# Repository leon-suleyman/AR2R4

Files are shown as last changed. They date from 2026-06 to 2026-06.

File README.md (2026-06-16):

# AR2R4

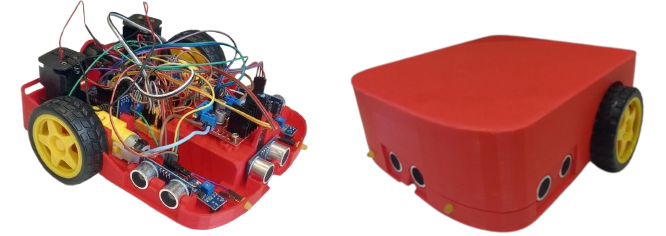
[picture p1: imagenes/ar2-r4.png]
Foto del robot AR2R4 con y sin la tapa puesta


El AR2R4 es un robot educativo de diseño abierto basado en
la placa Arduino UNO R4, orientado específicamente a la
enseñanza progresiva de programación y robótica móvil.
El robot fue concebido con el objetivo de ofrecer una
plataforma de muy bajo costo (se estima que el costo total es
USD 120, a precios de mayo de 2026), fácilmente reproducible
mediante impresión 3D y componentes comerciales accesibles,
pero al mismo tiempo suficientemente flexible como para cu-
brir distintos niveles de complejidad educativa y tecnológica.

## Componentes

Esta tabla contiene todos los componentes necesarios, el modelo utilizado y la cantidad necesaria para armar el AR2R4 cuyo modelo 3D está compartido en este repositorio.

| Componente | Modelo | Cantidad |
| --- | --- | --- |
| Arduino | UNO R4 | 1 |
| Puente H | L298N | 1 |
| Sensor óptico | LM393 | 2 |
| Sonar | HC-SR04 | 3 |
| Módulo IR | TCRT5000 | 2 |
| Resistencia | 10 $\Omega$, 1/4 W | 3 |
| Capacitor | 470 $\mu F$, 16 V | 1 |
| LED | 5mm | 3 |
| Motor DC | 3--6 V, doble eje | 2 |
| Rueda motriz | 68x26mm | 2 |
| Disco encoder | 25.5mm, 20 ranuras | 2 |
| Rueda castor | 25 mm | 1 |
| Breadboard | 170 puntos | 1 |
| Cable Dupont | 10cm macho-hembra | 34 |
| Cable Dupont | 10cm macho-macho | 13 |
| Cable | 1.5x100mm | 6 |
| Interruptor | 20mm | 1 |
| Tornillo | 3x12mm auto-perf. | 12 |
| Tornillo | 3x12mm cabeza plana | 2 |
| Tornillo | 3x30mm cabeza plana | 4 |
| Tuerca | 3mm | 6 |
| Porta pilas | 4xAA | 2 |
| Pila recargable | AA, 2700mAh | 8 |
| Chasis | PLA, 250g | 1 |

Al ser imprimible, el chasis puede ser modificado desde su modelo 3D y queda abierto a que modifiquen el AR2R4 de la manera que más les interese.

## Circuito

También les dejamos una imagen mostrando todas las conexiones eléctricas de este modelo del AR2R4, para que puedan recrearlo. Tengan en cuenta que los cables más gruesos son para conectar los motores al driver y el driver a las baterías.

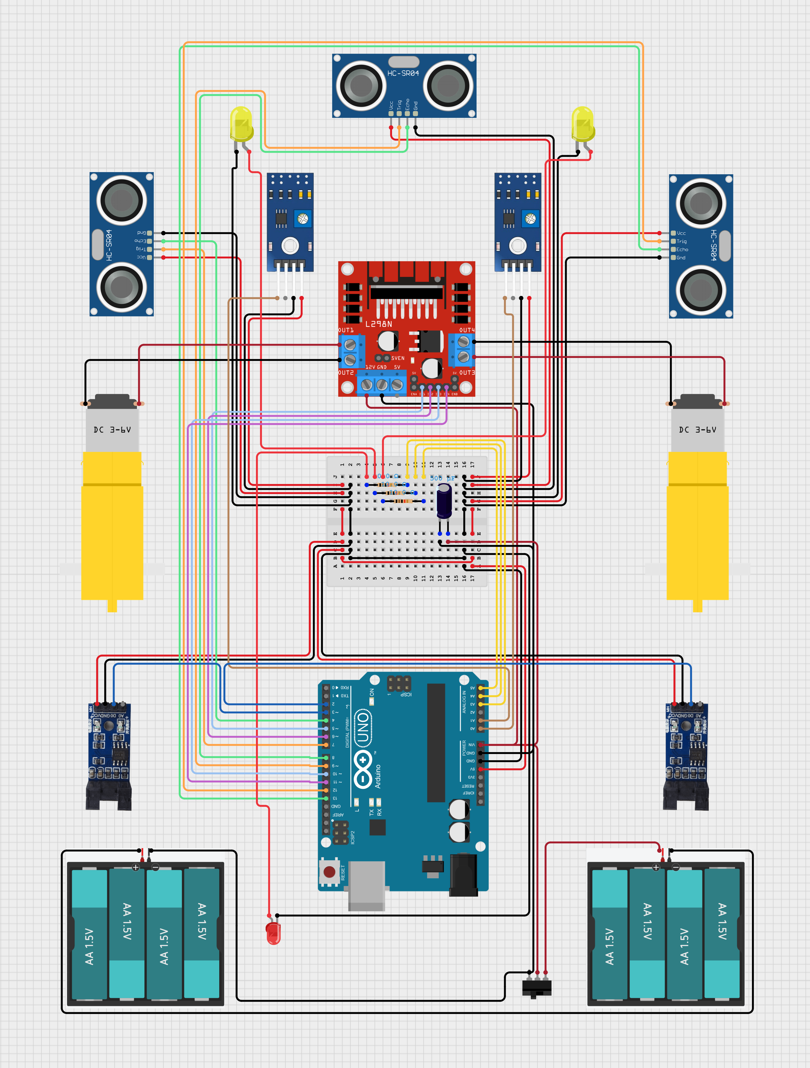
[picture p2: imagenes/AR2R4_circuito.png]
Diagrama de las conexiones de los componentes electrónicos del robot AR2R4


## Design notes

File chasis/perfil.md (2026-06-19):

# Perfil de impresión recomendado
* **IMPORTANTE**: En Orca y en BambuLab activar *Detect Thin Wall* (de otra forma, algunas secciones no se van a imprimir correctamente).
* Imprimir sin soportes (los modelos ya incluyen soportes).
* Imprimir sin infill (algunas secciones de los modelo son más delgadas intencionalmente, porque es donde se colocan los tornillos autoperforantes).
* Altura de capa: 0.2 mm.
* Altura de capa inicial: 0.4 mm.
* Capas de techo: 5.
* Capas de piso: 5.

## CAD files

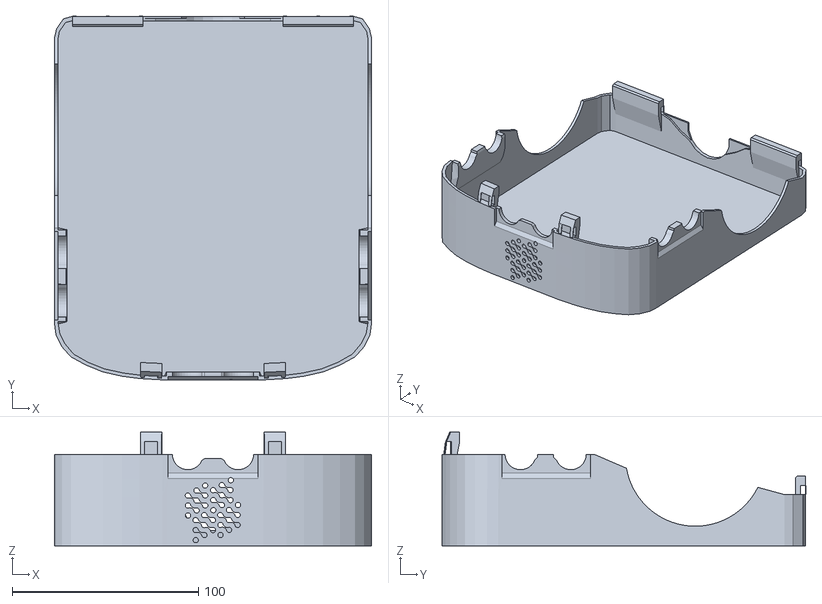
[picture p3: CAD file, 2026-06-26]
chasis/Tapa1.8.stl
170.0 x 195.1 x 60.9

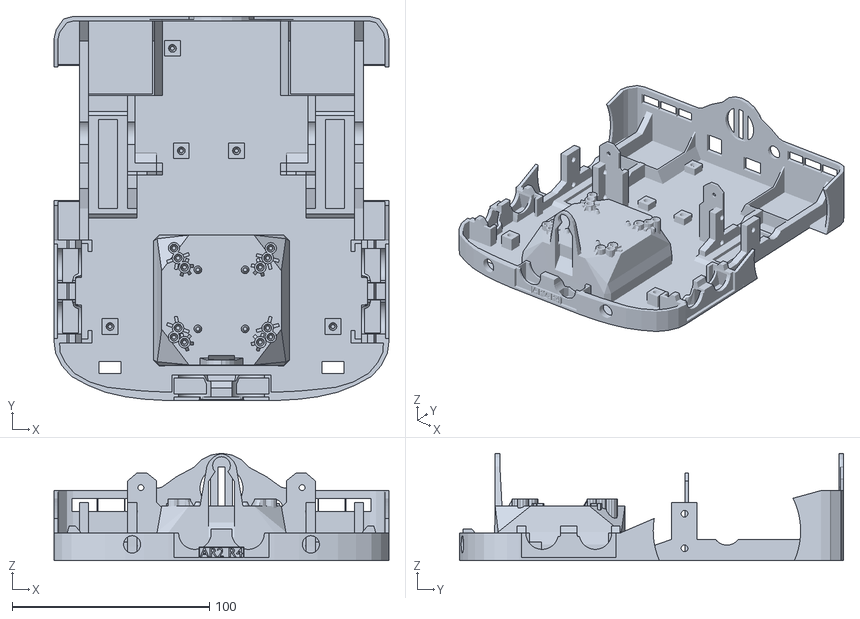
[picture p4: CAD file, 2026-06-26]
chasis/Base1.8.stl
170.0 x 195.0 x 54.5

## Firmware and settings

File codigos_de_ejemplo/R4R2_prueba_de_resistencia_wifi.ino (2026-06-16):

#include <Arduino.h>
#include <micro_ros_arduino.h>

#include <stdio.h>
#include <rcl/rcl.h>
#include <rcl/error_handling.h>
#include <rclc/rclc.h>
#include <rclc/executor.h>

#include <std_msgs/msg/float32.h>
#include <std_msgs/msg/int32.h>
#include <geometry_msgs/msg/twist.h>


/* ---- Pines motores (PWM) ---- */
#define PIN_MOTOR_IZQ_A 5
#define PIN_MOTOR_IZQ_B 6
#define PIN_MOTOR_DER_A 10
#define PIN_MOTOR_DER_B 11

/* ---- Pines encoders (interrupciones UNO) ---- */
#define PIN_ENCODER_DER 2  // INT0
#define PIN_ENCODER_IZQ 3   // INT1

/* ---- Pines sonares ---- */
#define T_SONAR_F 9
#define E_SONAR_F 8
#define T_SONAR_I 7
#define E_SONAR_I 4
#define T_SONAR_D 12
#define E_SONAR_D 13

/* ---- LEDs delanteros ---- */
#define LED_T A3
#define LED_IZQ A4
#define LED_DER A5

/* ---- Constantes sonar / comportamiento ---- */
const float DISTANCIA_SIN_ECO = 10000.0;
const float DIST_LLEGO_CM     = 5.0;    // <= 5 cm: llegó
const float DIST_MAX_DET_CM   = 50.0;   // si está más lejos: “no detecta”
const unsigned long BLINK_MS  = 200;    // parpadeo LEDs mientras se acerca

/* ---- PID / control ---- */
#define PWM_MAX 255
#define PWM_MIN_DER 30
#define PWM_MIN_IZQ 30
#define P 40.0
#define I 20.0
#define D 4.0
#define TIEMPO_CONTROL 50UL  // ms
#define VEL_BAJA 0.5
#define VEL_MEDIA 0.7
#define VEL_ALTA 0.9

static const int RANURAS_POR_VUELTA = 20; // 20 ticks = 1 vuelta

/*Medidas del coche (en metros)*/
#define DISTANCIA_ENTRE_RUEDAS 0.204
#define RADIO_DE_LAS_RUEDAS 0.0325

#if !defined(ESP32) && !defined(TARGET_PORTENTA_H7_M7) && !defined(ARDUINO_GIGA) && !defined(ARDUINO_NANO_RP2040_CONNECT) && !defined(ARDUINO_WIO_TERMINAL) && !defined(ARDUINO_UNOR4_WIFI) && !defined(ARDUINO_OPTA)
#error This example is only available for Arduino Portenta, Arduino Giga R1, Arduino Nano RP2040 Connect, ESP32 Dev module, Wio Terminal, Arduino Uno R4 WiFi and Arduino OPTA WiFi 
#endif

#if defined(LED_BUILTIN)
  #define LED_PIN LED_BUILTIN
#else
  #define LED_PIN 13
#endif

#define RCCHECK(fn) { rcl_ret_t temp_rc = fn; if((temp_rc != RCL_RET_OK)){error_loop();}}
#define RCSOFTCHECK(fn) { rcl_ret_t temp_rc = fn; if((temp_rc != RCL_RET_OK)){digitalWrite(LED_T, HIGH); delay(500); digitalWrite(LED_T, LOW);}}

/* Constantes de configuración */
float acumuladas_frontales[3] = {0,0,0};
int indice_frontales = 0;
float acumuladas_izquierdas[3] = {0,0,0};
int indice_izquierdas = 0;
float acumuladas_derechas[3] = {0,0,0};
int indice_derechas = 0;

/* ---- Estados y sonares ---- */
enum SONARES { SONAR_FRONTAL, SONAR_IZQ, SONAR_DER };
enum ESTADOS {AVANZAR, GIRAR_DER, GIRAR_IZQ, RETROCEDER};

ESTADOS estado = AVANZAR;

/* ---- Encoder ticks (ISR) ---- */
volatile long ticks_derecha = 0;
volatile long ticks_izquierda = 0;

/* Dirección recordada para dar signo a ticks
   Convención del robot (como tu actividad 5):
   - PWM NEGATIVO = ADELANTE
   - PWM POSITIVO = ATRÁS
   Para que la velocidad real sea POSITIVA cuando avanza,
   guardamos dir = +1 cuando PWM es negativo (adelante). */
volatile int8_t dir_der = +1; // +1 = adelante, -1 = atrás
volatile int8_t dir_izq = +1;

/* PID por rueda */
double integral_I_der = 0.0;
double integral_I_izq = 0.0;
double error_anterior_der = 0.0;
double error_anterior_izq = 0.0;

unsigned long tiempo_desde_control = 0;

/*variables de odometria*/
double posicion_x = 0.0;
double posicion_y = 0.0;
double posicion_theta = 0.0;

double velocidad_actual_lineal = 0.0;
double velocidad_actual_angular = 0.0;

/* Parpadeo LEDs */
unsigned long lastBlink = 0;
bool blinkOn = false;

/* Setpoints (velocidad deseada en grados/ms, SIEMPRE >= 0 para avanzar) */
double vel_deseada_der = 0.0;
double vel_deseada_izq = 0.0;

/* variables de micro-ros, publicadores y subscriptores */
String ros_namespace = "AR2R4";

rclc_support_t support;
rcl_allocator_t allocator;
rcl_node_t node;

rcl_publisher_t publisher_sonar_frontal;
std_msgs__msg__Float32 msg_sonar_frontal;
rcl_publisher_t publisher_sonar_derecho;
std_msgs__msg__Float32 msg_sonar_derecho;
rcl_publisher_t publisher_sonar_izquierdo;
std_msgs__msg__Float32 msg_sonar_izquierdo;

rcl_publisher_t publisher_velocidad_derecha;
std_msgs__msg__Float32 msg_velocidad_derecha;
rcl_publisher_t publisher_velocidad_izquierda;
std_msgs__msg__Float32 msg_velocidad_izquierda;

/*
rcl_publisher_t publisher_IR_derecho;
std_msgs__msg__Float32 msg_IR_derecho;
rcl_publisher_t publisher_IR_izquierdo;
std_msgs__msg__Float32 msg_IR_izquierdo;
*/

rcl_publisher_t publisher_odometria;
geometry_msgs__msg__Twist msg_odometria;

/* Prototipos */
void tick_encoder_derecha();
void tick_encoder_izquierda();

float sonar(int trigger, int echo);
float medir_sonar(int trigger, int echo, float acumuladas[], int &indice_acumuladas, rcl_publisher_t &publisher, std_msgs__msg__Float32 &msg);
float revisarSonares(int id_sonar);
bool detectaObjetivo(float d_cm);

void setup_micro_ros();

double calcular_velocidad(long ticks, unsigned long tiempo_ms);
void control_PID(const unsigned long dt_ms);
int ciclo_control_PID_mag(double vel_deseada, double vel_real,
                          double& integral_I, double& error_previo);

void aplicar_PWM(int pwm_izq, int pwm_der);
void aplicar_PWM_a_motor(int pwm, uint8_t pin_A, uint8_t pin_B);

void cambiar_estado(int sonarActivo, float distActiva);

void calcular_posicion_actual(const unsigned long dt_ms);

void error_loop(){
  while(1){
    digitalWrite(LED_T, !digitalRead(LED_T));
    digitalWrite(LED_DER, !digitalRead(LED_DER));
    digitalWrite(LED_IZQ, !digitalRead(LED_IZQ));
    delay(100);
  }
}

/*
void timer_callback(rcl_timer_t * timer, int64_t last_call_time)
{
  RCLC_UNUSED(last_call_time);
  if (timer != NULL) {
    RCSOFTCHECK(rcl_publish(&publisher, &msg, NULL));
  }
}
*/

int tiempo_giro = 0;

/* =========================
   SETUP
   ========================= */
void setup() {
  pinMode(PIN_MOTOR_IZQ_A, OUTPUT);
  pinMode(PIN_MOTOR_IZQ_B, OUTPUT);
  pinMode(PIN_MOTOR_DER_A, OUTPUT);
  pinMode(PIN_MOTOR_DER_B, OUTPUT);

  pinMode(T_SONAR_I, OUTPUT); pinMode(E_SONAR_I, INPUT);
  pinMode(T_SONAR_F, OUTPUT); pinMode(E_SONAR_F, INPUT);
  pinMode(T_SONAR_D, OUTPUT); pinMode(E_SONAR_D, INPUT);

  pinMode(LED_T, OUTPUT);
  pinMode(LED_IZQ, OUTPUT);
  pinMode(LED_DER, OUTPUT);

  pinMode(PIN_ENCODER_DER, INPUT);
  pinMode(PIN_ENCODER_IZQ, INPUT);

  attachInterrupt(digitalPinToInterrupt(PIN_ENCODER_DER), tick_encoder_derecha, RISING);
  attachInterrupt(digitalPinToInterrupt(PIN_ENCODER_IZQ), tick_encoder_izquierda, RISING);

  //Serial.begin(9600);
  digitalWrite(LED_T, HIGH);
  delay(500);
  digitalWrite(LED_T, LOW);
  setup_micro_ros();
  
  aplicar_PWM(0, 0);
  tiempo_desde_control = millis();
  vel_deseada_der = -VEL_MEDIA;
  vel_deseada_izq = VEL_MEDIA;
  estado = GIRAR_IZQ;
  //aplicar_PWM(0,53);
}

/* =========================
   LOOP
   ========================= */
void loop() {

  //revisamos nuestros sonares y vemos si tenemos objetos cercanos 
  float sonar_frontal = revisarSonares(SONAR_FRONTAL);
  float sonar_izquierdo = revisarSonares(SONAR_IZQ);
  float sonar_derecho = revisarSonares(SONAR_DER);
  //Serial.print("frontal: "); Serial.print(sonar_frontal);Serial.print("izquierdo: "); Serial.print(sonar_izquierdo);Serial.print("derecho: "); Serial.println(sonar_derecho);

  bool obj_frente = hay_algo_cerca(sonar_frontal);
  bool obj_izquierda = hay_algo_cerca(sonar_izquierdo);
  bool obj_derecha = hay_algo_cerca(sonar_derecho);

  
  //en base a que objetos tenemos cercanos, cambiamos nuestro estado
  cambiar_estado(obj_frente, obj_izquierda, obj_derecha);
  long tiempo = millis();
  if (tiempo - tiempo_desde_control >= TIEMPO_CONTROL) {
    long dt_ms = tiempo - tiempo_desde_control;
    tiempo_desde_control = tiempo;
    calcular_posicion_actual(dt_ms);
    control_PID(dt_ms);
  }
}

void setup_micro_ros(){
  //parametros de set_microros_wifi_transorts: ("Nombre de red WIFI a conectar", "Contraseña de red WIFI", "IP de la computadora donde corre el agente de micro-ros donde comunicar", "puerto por el que el agente de micro-ros está conectado")
  set_microros_wifi_transports("EVENTO", "UBA-2022", "10.142.7.135", 8888);

  //Señal de que se conectó bien a la red WiFi
  digitalWrite(LED_T, HIGH);
  delay(500);
  digitalWrite(LED_T, LOW);
  //delay para estabilizar conexión con el agente de micro-ros
  delay(1500);

  allocator = rcl_get_default_allocator();

  //create init_options
  RCCHECK(rclc_support_init(&support, 0, NULL, &allocator));

  // create node
  RCCHECK(rclc_node_init_default(&node, "AR2R4", "", &support));
  String topic_name = "";

  // create publisher
  topic_name = ros_namespace + "/sonar_frontal";
  RCCHECK(rclc_publisher_init_best_effort(
    &publisher_sonar_frontal,
    &node,
    ROSIDL_GET_MSG_TYPE_SUPPORT(std_msgs, msg, Float32), 
    topic_name.c_str()));

  msg_sonar_frontal.data = 0.0;

  topic_name = ros_namespace + "/sonar_derecho";
  RCCHECK(rclc_publisher_init_best_effort(
    &publisher_sonar_derecho,
    &node,
    ROSIDL_GET_MSG_TYPE_SUPPORT(std_msgs, msg, Float32),
    topic_name.c_str()));

  msg_sonar_derecho.data = 0.0;
  
  topic_name = ros_namespace + "/sonar_izquierdo";
  RCCHECK(rclc_publisher_init_best_effort(
    &publisher_sonar_izquierdo,
    &node,
    ROSIDL_GET_MSG_TYPE_SUPPORT(std_msgs, msg, Float32),
    topic_name.c_str()));

  msg_sonar_izquierdo.data = 0.0;

  topic_name = ros_namespace + "/velocidad_derecha";
  RCCHECK(rclc_publisher_init_best_effort(
    &publisher_velocidad_derecha,
    &node,
    ROSIDL_GET_MSG_TYPE_SUPPORT(std_msgs, msg, Float32),
    topic_name.c_str()));

  msg_velocidad_derecha.data = 0.0;

  topic_name = ros_namespace + "/velocidad_izquierda";
  RCCHECK(rclc_publisher_init_best_effort(
    &publisher_velocidad_izquierda,
    &node,
    ROSIDL_GET_MSG_TYPE_SUPPORT(std_msgs, msg, Float32),
    topic_name.c_str()));

  msg_velocidad_izquierda.data = 0.0;

  /* 
  topic_name = ros_namespace + "/IR_derecho";
  RCCHECK(rclc_publisher_init_best_effort(
    &publisher_IR_derecho,
    &node,
    ROSIDL_GET_MSG_TYPE_SUPPORT(std_msgs, msg, Float32),
    topic_name.c_str()));

  msg_IR_derecho.data = 0.0;

 topic_name = ros_namespace + "/IR_izquierdo";
  RCCHECK(rclc_publisher_init_best_effort(
    &publisher_IR_izquierdo,
    &node,
    ROSIDL_GET_MSG_TYPE_SUPPORT(std_msgs, msg, Float32),
    topic_name.c_str()));

  msg_IR_izquierdo.data = 0.0;
  */

  topic_name = ros_namespace + "/odometria";
  RCCHECK(rclc_publisher_init_best_effort(
    &publisher_odometria,
    &node,
    ROSIDL_GET_MSG_TYPE_SUPPORT(geometry_msgs, msg, Twist),
    topic_name.c_str()));

  msg_odometria.linear.x = 0.0;
  msg_odometria.linear.y = 0.0;
  msg_odometria.linear.z = 0.0;

  msg_odometria.angular.x = 0.0;
  msg_odometria.angular.y = 0.0;
  msg_odometria.angular.z = 0.0;
}

void cambiar_estado(bool objeto_al_frente, bool objeto_a_la_izquierda, bool objeto_a_la_derecha){
  int t = millis();
    //dependiendo de nuestro estado actual, reaccionamos diferente:
    switch(estado){
        case AVANZAR:
            //Si el hay un objeto en frente, cambiamos al estado RETROCEDER y movemos las ruedas para atras.
            if(objeto_al_frente){
                estado = RETROCEDER;
                digitalWrite(LED_T, HIGH);
                vel_deseada_der =   VEL_ALTA;
                vel_deseada_izq =   VEL_BAJA;
                integral_I_der = 0.0;
                integral_I_izq = 0.0;
            }else{
                //Si no hay un objeto en frente, revisamos si hay un objeto a la izquierda o derecha y de haberlo giramos al lado correspondiente.
                if(objeto_a_la_derecha && !objeto_a_la_izquierda){
                    estado = GIRAR_IZQ;
                    digitalWrite(LED_IZQ, HIGH);
                    vel_deseada_der =  -VEL_BAJA;
                    vel_deseada_izq =   VEL_BAJA;
                    integral_I_izq = 0.0;
                }
                if(!objeto_a_la_derecha && objeto_a_la_izquierda){
                    estado = GIRAR_DER;
                    digitalWrite(LED_DER, HIGH);
                    vel_deseada_der =   VEL_BAJA;
                    vel_deseada_izq =  -VEL_BAJA;
                    integral_I_der = 0.0;
                }
            }
            break;

        case GIRAR_IZQ:
            //si ya no hay un objeto a la derecha o hay un objeto a ambos lado, avanzamos
            /*
            if(!objeto_a_la_derecha || (objeto_a_la_derecha && objeto_a_la_izquierda)){
                estado = AVANZAR;
                digitalWrite(LED_IZQ, LOW);
                vel_deseada_der =  -VEL_MEDIA;
                vel_deseada_izq =  -VEL_MEDIA;
                integral_I_izq = 0.0;
            }
            */
            if(t - tiempo_giro > 5000){
              tiempo_giro = t;
              estado = GIRAR_DER;
              digitalWrite(LED_IZQ, LOW);
              digitalWrite(LED_DER, HIGH);
              vel_deseada_der =  VEL_MEDIA;
              vel_deseada_izq =  -VEL_MEDIA;
            }
            break;

        case GIRAR_DER:
            //si ya no hay un objeto a la izquierda o hay un objeto a ambos lados, avanzamos
            /*
            if(!objeto_a_la_izquierda || (objeto_a_la_izquierda && objeto_a_la_derecha)){
                estado = AVANZAR;
                digitalWrite(LED_DER, LOW);
                vel_deseada_der =  -VEL_MEDIA;
                vel_deseada_izq =  -VEL_MEDIA;
                integral_I_der = 0.0;
            }
            */
            if(t - tiempo_giro > 5000){
              tiempo_giro = t;
              estado = GIRAR_IZQ;
              digitalWrite(LED_DER, LOW);
              digitalWrite(LED_IZQ, HIGH);
              vel_deseada_der =  -VEL_MEDIA;
              vel_deseada_izq =  VEL_MEDIA;
            }
            break;

        case RETROCEDER:
            //si ya no hay un objeto al frente, giramos a la izquierda por 0,2 segundos y luego cambiamos a avanzar
            if(!objeto_al_frente){
                estado = AVANZAR;
                digitalWrite(LED_T, LOW);
                vel_deseada_der =  -VEL_MEDIA;
                vel_deseada_izq =  -VEL_MEDIA;
                integral_I_der = 0.0;
                integral_I_izq = 0.0;
            }
            break;
    }
    //Serial.print("Estado actual: "); Serial.println(print_estado(estado));
    return;
}

String print_estado(ESTADOS est){
  String res = "";
  switch(est){
    case AVANZAR:
      res = "AVANZAR";
      break;
    case GIRAR_IZQ:
      res = "GIRAR_IZQ";
      break;
    case GIRAR_DER:
      res = "GIRAR_DER";
      break;
    case RETROCEDER:
      res = "RETROCEDER";
      break;
  }
  return res;
}

/* Odometria */
void calcular_posicion_actual(long dt_ms){
  double delta_izq = M_PI * 2 * RADIO_DE_LAS_RUEDAS * ticks_izquierda / RANURAS_POR_VUELTA;
  double delta_der = M_PI * 2 * RADIO_DE_LAS_RUEDAS * ticks_derecha / RANURAS_POR_VUELTA;

  double delta_theta = (delta_der - delta_izq) / DISTANCIA_ENTRE_RUEDAS;
  double delta_distancia = (delta_izq + delta_der) / 2;

  double delta_x = delta_distancia * cos( posicion_theta );
  double delta_y = delta_distancia * sin( posicion_theta );

  double delta_t = (double) dt_ms;

  posicion_x += delta_x;
  posicion_y += delta_y;
  posicion_theta += delta_theta;
  posicion_theta = posicion_theta - (360 * floor(posicion_theta/360.0));

  velocidad_actual_lineal = delta_distancia / delta_t;
  velocidad_actual_angular = posicion_theta / delta_t;

  msg_odometria.linear.x = posicion_x;
  msg_odometria.linear.y = posicion_y;

  msg_odometria.angular.z = posicion_theta;

  RCSOFTCHECK(rcl_publish(&publisher_odometria, &msg_odometria, NULL));
}

/* =========================
   PID (devuelve magnitud 0..255)
   ========================= */

void control_PID(long dt_ms){
  // Copia atómica de ticks (evita que cambien en medio de la lectura)
  long ticks_der_local, ticks_izq_local;
  noInterrupts();
  ticks_der_local = ticks_derecha;
  ticks_izq_local = ticks_izquierda;
  ticks_derecha = 0;
  ticks_izquierda = 0;
  interrupts();

  // Velocidad actual (con signo) en grados/ms
  const double vel_actual_der = calcular_velocidad(ticks_der_local, dt_ms, dir_der);
  msg_velocidad_derecha.data = vel_actual_der;
  const double vel_actual_izq = calcular_velocidad(ticks_izq_local, dt_ms, dir_izq);
  msg_velocidad_izquierda.data = vel_actual_izq;

  RCSOFTCHECK(rcl_publish(&publisher_velocidad_derecha, &msg_velocidad_derecha, NULL));
  RCSOFTCHECK(rcl_publish(&publisher_velocidad_izquierda, &msg_velocidad_izquierda, NULL));
  // PID por rueda -> PWM con signo
  int pwm_der = ciclo_control_PID(vel_deseada_der, vel_actual_der, integral_I_der, error_anterior_der, PWM_MIN_DER);
  int pwm_izq = ciclo_control_PID(vel_deseada_izq, vel_actual_izq, integral_I_izq, error_anterior_izq, PWM_MIN_IZQ);

  // Recordar dirección por software para que el encoder tenga signo
  // Convención: PWM > 0 => adelante, PWM < 0 => atrás
  noInterrupts();
  dir_der = (pwm_der >= 0) ? +1 : -1;
  dir_izq = (pwm_izq >= 0) ? +1 : -1;
  interrupts();

  aplicar_PWM(pwm_izq, pwm_der);
  /*
  Serial.print("dt(ms)="); Serial.print(dt_ms);
  Serial.print(" | vel_izq="); Serial.print(vel_actual_izq, 4);
  Serial.print(" | vel_der="); Serial.print(vel_actual_der, 4);
  Serial.print(" | pwm_izq="); Serial.print(pwm_izq);
  Serial.print(" | pwm_der="); Serial.println(pwm_der);
  Serial.print(" | encoder_izq="); Serial.print(ticks_izq_local);
  Serial.print(" | encoder_der="); Serial.println(ticks_der_local);
  */
  // Debug útil

  return;
}


double calcular_velocidad(long ticks, unsigned long tiempo_ms, int direccion) {
  if (tiempo_ms == 0) return 0.0;

  // ticks/ms (con signo)
  const double ticks_por_ms = (double)ticks / (double)tiempo_ms;

  // ticks -> grados: (ticks / ranuras_por_vuelta) * 360
  const double grados_por_ms = ticks_por_ms * 360.0 / (double)RANURAS_POR_VUELTA;
  return grados_por_ms * direccion;
}

int ciclo_control_PID(double vel_deseada, double vel_real, double& integral_I, double& error_previo, int pwm_min) {
  const double error_actual = vel_deseada - vel_real;

  // P
  const double termino_P = P * error_actual;

  // I (anti-windup por saturación del acumulador)
  integral_I += error_actual;
  const double LIM_I = (double)PWM_MAX / (I > 0.0 ? I : 1.0); // límite razonable para integral
  if (integral_I > LIM_I) integral_I = LIM_I;
  if (integral_I < -LIM_I) integral_I = -LIM_I;
  const double termino_I = I * integral_I;

  // D
  const double termino_D = D * (error_actual - error_previo);
  error_previo = error_actual;

  // Salida PID
  double pwm_pid = termino_P + termino_I + termino_D;

  // Saturación a rango PWM
  if (pwm_pid > (double)PWM_MAX) pwm_pid = (double)PWM_MAX;
  if (pwm_pid < -(double)PWM_MAX) pwm_pid = -(double)PWM_MAX;

  // "Deadzone" opcional: PWM_MIN (aquí PWM_MIN=0, pero lo dejamos por claridad)
  
  const int signo = (pwm_pid > 0.0) ? +1 : ((pwm_pid < 0.0) ? -1 : 0);
  int pwm_out = (pwm_pid < 1 && pwm_pid > -1) ? 0 : (int)pwm_pid + (pwm_min * signo);


  if (pwm_out > PWM_MAX) pwm_out = PWM_MAX;
  if (pwm_out < -PWM_MAX) pwm_out = -PWM_MAX;

  return pwm_out;
}

void tick_encoder_derecha() {
  // Sumar ticks con signo según dirección recordada
  ticks_derecha ++;
}

void tick_encoder_izquierda() {
  ticks_izquierda ++;
}

/* =========================
   Motores (PWM con signo)
   NEGATIVO = adelante, POSITIVO = atrás (como tu actividad 5)
   ========================= */
void aplicar_PWM(int pwm_izq, int pwm_der) {
  //Serial.print("Izquierda: "); Serial.print(pwm_izq); Serial.print(" Derercha: "); Serial.println(pwm_der);
  aplicar_PWM_a_motor(pwm_izq, PIN_MOTOR_IZQ_A, PIN_MOTOR_IZQ_B);
  aplicar_PWM_a_motor(pwm_der, PIN_MOTOR_DER_A, PIN_MOTOR_DER_B);
}

void aplicar_PWM_a_motor(int pwm, uint8_t pin_A, uint8_t pin_B) {
  if (pwm > PWM_MAX) pwm = PWM_MAX;
  if (pwm < -PWM_MAX) pwm = -PWM_MAX;

  int pwm_A = 0, pwm_B = 0;

  if (pwm > 0) {         // atrás
    pwm_A = pwm;
    pwm_B = 0;
  } else if (pwm < 0) {  // adelante
    pwm_A = 0;
    pwm_B = -pwm;
  }

  analogWrite(pin_A, pwm_A);
  analogWrite(pin_B, pwm_B);
}


float sonar(int trigger, int echo) {
  float pulse_duration;
  /* silenciamos para que no haya interferecia */
  digitalWrite(trigger, LOW);
  delayMicroseconds(5);
  /* mandamos la señal */
  digitalWrite(trigger, HIGH);
  delayMicroseconds(10);
  digitalWrite(trigger, LOW);
  /* esperamos a escuchar el éco, cuando llega medimos cuanto dura*/
  pulse_duration = pulseIn(echo, HIGH, 14550);
  /* devovlemos la medición de distancia en centimetros */

  if (pulse_duration == 0) return DISTANCIA_SIN_ECO;
  else return pulse_duration / 58.2;
  
}

float medir_sonar(int trigger, int echo, float acumuladas[], int &indice_acumuladas, rcl_publisher_t &publisher, std_msgs__msg__Float32 &msg){
  float lectura_sonar = sonar(trigger, echo);
  acumuladas[indice_acumuladas] = lectura_sonar;
  indice_acumuladas = (indice_acumuladas + 1) % 3;
  lectura_sonar = 0;
  for(int i = 0; i < 3; i++){
    lectura_sonar += acumuladas[i];
  }
  lectura_sonar = lectura_sonar / 3;
  msg.data = lectura_sonar;
  RCSOFTCHECK(rcl_publish(&publisher, &msg, NULL));
  return lectura_sonar;
}

float revisarSonares(int id_sonar) {
  float lectura_sonar;
  lectura_sonar = 10000;
  if (id_sonar == SONAR_FRONTAL) {
    lectura_sonar = medir_sonar(T_SONAR_F, E_SONAR_F, acumuladas_frontales, indice_frontales, publisher_sonar_frontal, msg_sonar_frontal);
  } else {
    if (id_sonar == SONAR_DER) {
        lectura_sonar = medir_sonar(T_SONAR_D, E_SONAR_D, acumuladas_derechas, indice_derechas, publisher_sonar_derecho, msg_sonar_derecho);
    } else {
      if (id_sonar == SONAR_IZQ) {
        lectura_sonar = medir_sonar(T_SONAR_I, E_SONAR_I, acumuladas_izquierdas, indice_izquierdas, publisher_sonar_izquierdo, msg_sonar_izquierdo);
        }
    }
  }

  return lectura_sonar;
}

bool hay_algo_cerca(float distancia) {
  return (distancia <= 25);
}

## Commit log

2026-06-11 Circuito y README
2026-06-16 tabla de componentes para el readme
2026-06-16 texto sobre la tabla y el circuito
2026-06-16 intentando que quede el mu
2026-06-16 Agrego modelos 3D
    [Base1.7.stl, Tapa1.7.stl]
2026-06-19 Agrego info sobre el perfil de impresión recomendado para el chasis
2026-06-26 Actualizo el modelo del chasis
    [Base1.7.stl, Base1.8.stl, Tapa1.7.stl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]
